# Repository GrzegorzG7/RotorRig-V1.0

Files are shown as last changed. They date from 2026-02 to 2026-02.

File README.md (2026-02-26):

# RotorRig — DIY BLDC Motor & Prop Test Bench

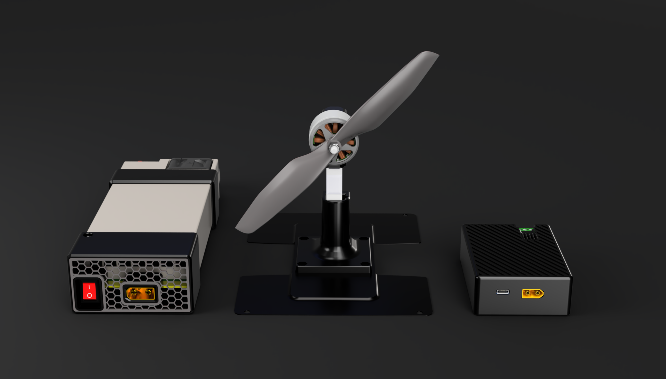
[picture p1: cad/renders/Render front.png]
RotorRig CAD render


RotorRig is a compact DIY platform for **repeatable testing of BLDC motors and propellers**.  
It streams data over USB as **CSV**, so you can compare setups (motor/prop/ESC/voltage) with real numbers instead of “feels faster”.

**What it does:**
- **Thrust**: load cell + HX711  
- **Electrical**: voltage / current / power via INA226 + shunt  
- **RPM**: BDShot telemetry (when ESC/firmware supports it)  
- **Logging**: CSV over Serial (examples in `logs/examples/`)

Full build journey + context: https://blueprint.hackclub.com/projects/7240

---

## Why I made it
I built RotorRig to get **repeatable, apples-to-apples comparisons** between motors and props (and later: to validate experiments like custom windings/stators).  
With the same test profile and measurement chain, it’s much easier to judge performance, efficiency, and tuning changes objectively.

---

## Safety
This spins real props — treat it like a power tool.
- Keep a clear area around the rig
- Wear eye protection
- Secure the rig to a heavy base
- First tests: low throttle / no prop

---

## Repository structure
- `cad/`
  - `export_step/` → full assembly `.STEP`
  - `source/` → Fusion 360 source `.f3z`
  - `stl/` → printable STLs
  - `renders/` → renders used below
- `docs/`
  - `images/` → build photos
  - `wiring/` → wiring diagram
- `kicad/` → schematic / connections in KiCad
- `firmware/` → PlatformIO project (RP2040)
- `logs/examples/` → example CSV logs
- `BOM.csv` → full BOM

---

## Pictures

### CAD renders
<p align="center">
  
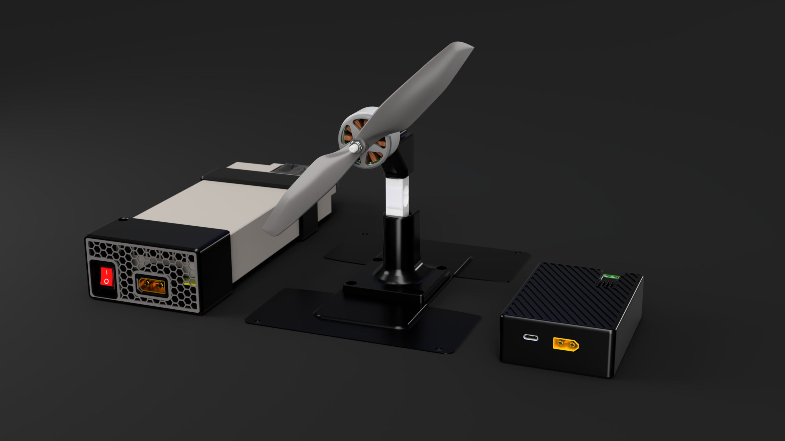
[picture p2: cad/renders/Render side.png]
  
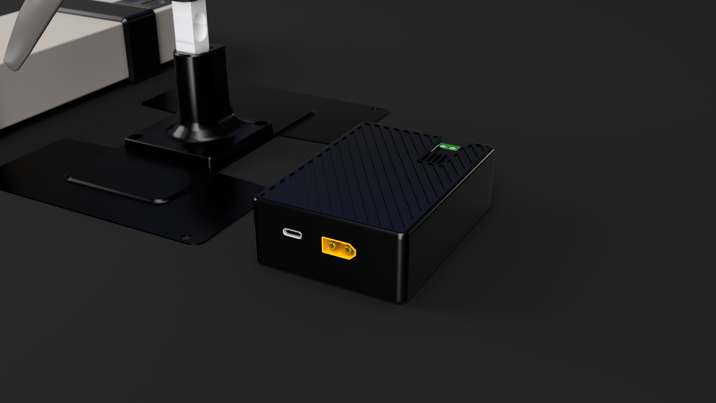
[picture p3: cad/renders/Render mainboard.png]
  
</p>

### Build photos
<p align="center">
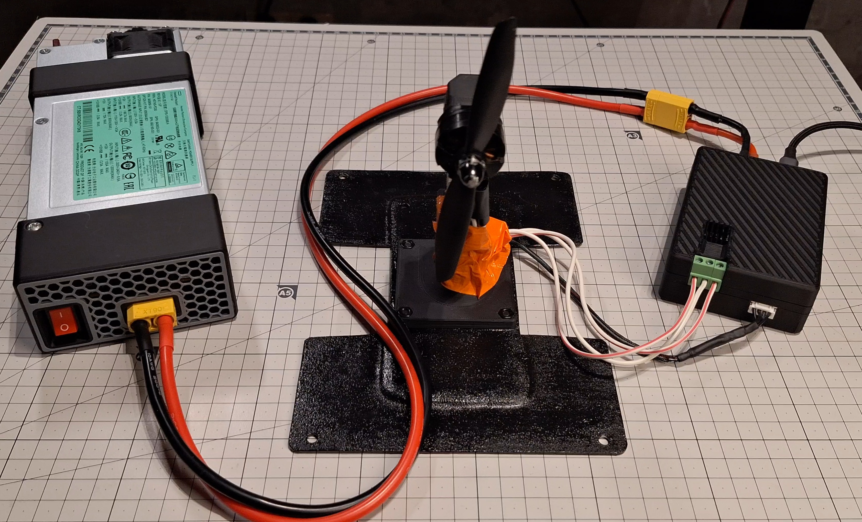
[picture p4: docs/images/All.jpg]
  
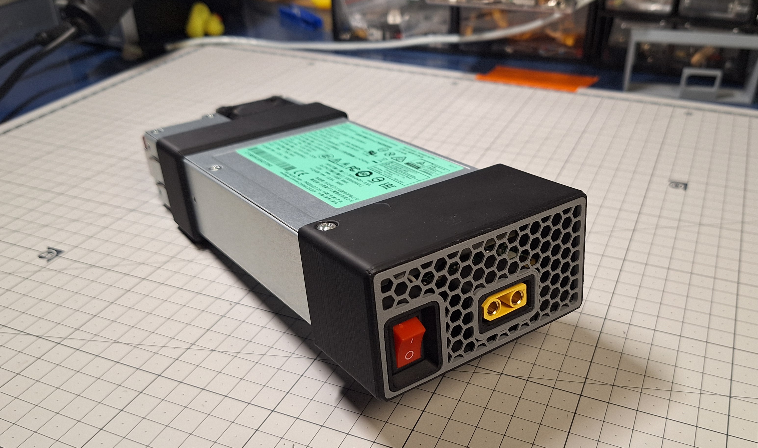
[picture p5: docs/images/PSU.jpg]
  
</p>
<p align="center">
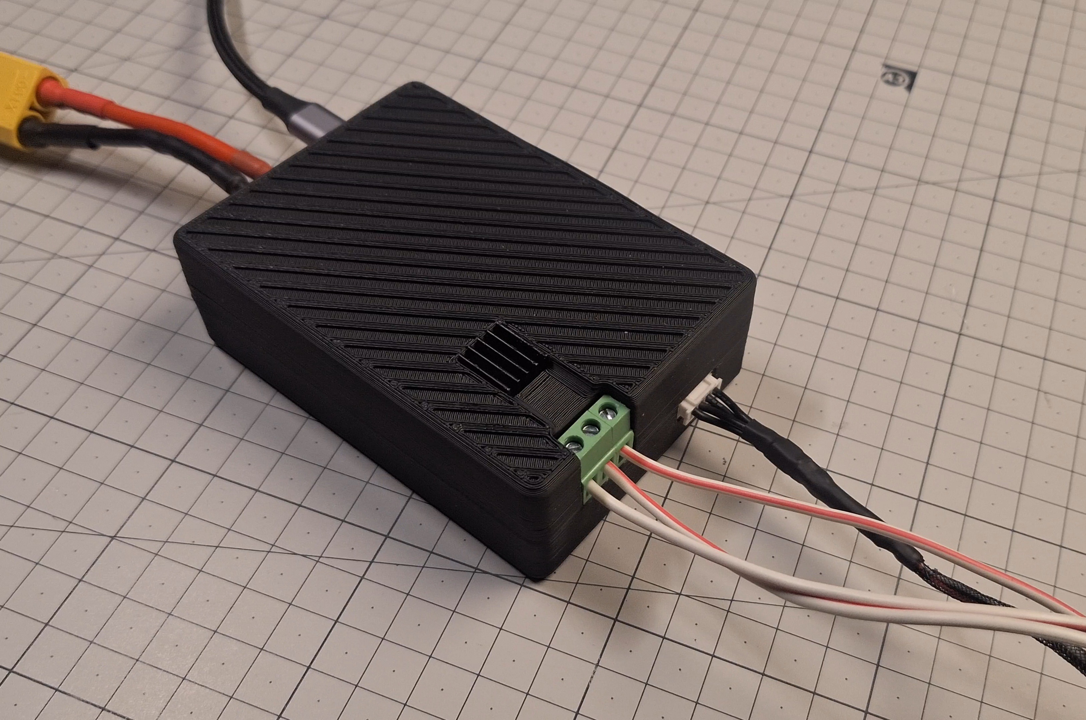
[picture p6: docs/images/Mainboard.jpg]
  
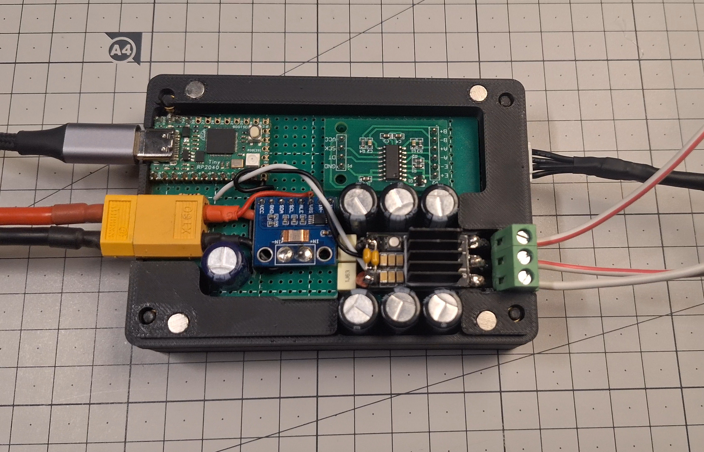
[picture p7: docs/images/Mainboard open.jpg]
  
</p>

### Wiring diagram
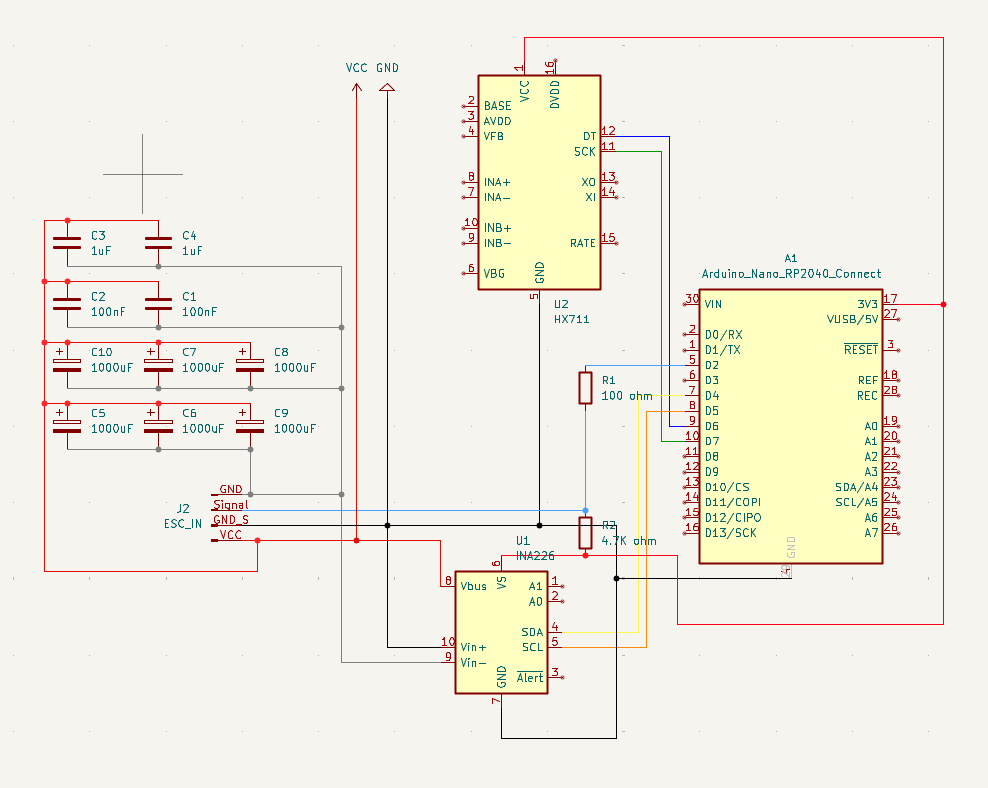
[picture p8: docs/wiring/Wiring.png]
Wiring diagram


---

## How to build (from scratch)

### 1) 3D print the parts
All STLs are in `cad/stl/`:
- `cad/stl/Bench/` (load cell holders)
- `cad/stl/Mainboard/` (electronics enclosure)
- `cad/stl/Power supply/` (PSU stand/cover)

**Print settings used (my build):**

**ABS / ABS+ (enclosures + structural parts)**
- Layer height: **0.2 mm**
- Walls: **4**
- Infill: **40%**

**TPU (rubber feet)**
- Layer height: **0.2 mm**
- Walls: **2**
- Infill: **100%**

Hardware (inserts/screws/magnets): see **BOM**.

### 2) Mechanical assembly
- Mount the load cell using the printed holders (bench parts are in `cad/stl/Bench/`)
- Mount the motor securely and keep the thrust direction aligned with the load cell
- Make sure nothing can touch the prop (wires, zip-ties, enclosure edges, etc.)

### 3) Electronics & wiring
This version uses **perfboard + off-the-shelf modules** (no custom manufactured PCB required).
- Wiring diagram: `docs/wiring/Wiring.png`
- KiCad project files are in `kicad/` (Mainboard.kicad_pro + Mainboard.kicad_sch)

### 4) Firmware (PlatformIO)
Target MCU: **WisdPi Tiny RP2040** (RP2040).  
The PlatformIO environment is set up as `board = pico`, which works for Pico-class RP2040 boards.

From the `firmware/` directory:

```bash
pio run -t upload
```

Serial monitor (115200):

```bash
pio device monitor
```

---

## How to use (typical workflow)

### 1) Connect everything
- motor ↔ ESC ↔ PSU/battery  
- RP2040 ↔ USB to PC  

Open Serial @ **115200**.

### 2) Set metadata (saved into every CSV row)
```text
setmeta <test_id> <motor_id> <kv> <prop> <battery_s> <esc_fw> <pole_pairs>
```

Example:
```text
setmeta T_CORE M_3115 900 APC8x4E 4 LANRC45A 7
```

### 3) Calibration / tare
- **Calibration** (`cal ...` + `save`) is usually done **once** (or after hardware changes).
- **Tare** should be done **before each test**.

Tare:
```text
tare
```

If you need to calibrate:
```text
cal <mass_g>
save
```

### 4) Run a test (core profile)
```text
start
autotest core
```

Stop anytime:
```text
stop
```

Emergency stop:
```text
estop
```

Command list:
```text
help
```

---

## CSV logs
RotorRig prints CSV rows over Serial. Example logs are in `logs/examples/`.

The CSV header includes (among others):
- `throttle_pct`, `RPM`, `V_bus_V`, `I_A`, `P_in_W`, `thrust_g`, `eff_g_per_W`, and metadata from `setmeta`.

---

## BOM (Bill of Materials)
Full BOM is in `BOM.csv`.

| Line | Category | Qty | Unit | Part | Manufacturer | MPN | Link |
|---:|---|---:|---|---|---|---|---|
| 1 | MCU / Control | 1 | pcs | Tiny RP2040 dev board (RP2040) | WisdPi | Tiny RP2040 (WP-2040T) | https://www.wisdpi.com/products/wisdpi-tiny-rp2040-a-tiny-cool-rp2040-dev-board-with-4mb-flash |
| 2 | Drive | 1 | pcs | ESC 45A 2–6S (BLHeli_S / DShot) | LANRC | LANRC 45A BLHeli_S 2-6S ESC | https://pl.banggood.com/LANRC-35A-or-45A-BLHeli_S-2-6S-ESC-with-RGB-LEDs-Supports-DShot150-300-600-for-FPV-Racing-Drone-p-2045658.html |
| 3 | Sensing | 1 | pcs | HX711 load cell amplifier module (24-bit ADC) | Generic / Kamami | HX711 module | https://kamami.pl/czujniki-nacisku/561387-wzmacniacz-konwerter-sygnalu-tensometru-z-ukladem-hx711-5906623473342.html |
| 4 | Sensing | 1 | pcs | INA226 current/voltage/power monitor module (I2C) | Generic / Kamami | INA226 module | https://kamami.pl/en/current-sensors/573164-module-with-ina226-current-sensor-5906623456505.html |
| 5 | Sensing | 1 | pcs | Load cell 10kg straight bar (TAL220 type) | SparkFun | SEN-13329 (TAL220 10kg) | https://www.sparkfun.com/load-cell-10kg-straight-bar-tal220.html |
| 6 | Power (DC-link) | 6 | pcs | Electrolytic capacitor low-ESR 1000µF 25V (DC-link bank) | Panasonic | EEUFR1E102B | https://www.tme.eu/en/details/eeufr1e102b/tht-electrolytic-capacitors/panasonic/ |
| 7 | Power (HF decoupling) | 2 | pcs | MLCC capacitor 1µF 50V X7R 1206 (near ESC) | Yageo | CC1206KKX7R9BB105 | https://www.tme.eu/pl/details/cc1206kkx7r9105/kondensatory-mlcc-smd/yageo/cc1206kkx7r9bb105/ |
| 8 | Power (snubber) | 2 | pcs | Film capacitor 100nF 63V (snubber/HF) | KEMET | R82DC3100AA50K | https://www.tme.eu/pl/details/r82dc3100aa50k/kondensatory-foliowe-tht/kemet/ |
| 9 | Passives | 1 | pcs | Resistor 100Ω 0.25W 1% THT | ROYALOHM | MF0S4FF1000A50 | https://www.tme.eu/en/details/mf0s4ff1000a50/tht-resistors/royalohm/ |
| 10 | Passives | 1 | pcs | Resistor 4.7kΩ 0.25W 1% THT | ROYALOHM | MF0S4FF4701A50 | https://www.tme.eu/en/details/mf0s4ff4701a50/tht-resistors/royalohm/ |
| 11 | PSU mod | 1 | pcs | Resistor 13.3kΩ 0.25W 1% THT (voltage adjust mod) | ROYALOHM | MF0S4FF1332A50 | https://www.tme.eu/lv/details/mf0s4ff1332a50/rezistori-tht/royalohm/ |
| 12 | PSU mod | 1 | pcs | Resistor 47kΩ 0.25W 1% THT (OVP adjust mod) | ROYALOHM | MF0S4FF4702A50 | https://www.tme.eu/en/details/mf0s4ff4702a50/tht-resistors/royalohm/ |
| 13 | INA226 shunt | 1 | pcs | Current sense resistor 1mΩ 3W 1% 2512 | Bourns | CRE2512-FZ-R001E-3 | https://www.digikey.com/en/products/detail/bourns-inc/CRE2512-FZ-R001E-3/4900069 |
| 14 | Connectors | 1 | pair | XT60 connector pair (male+female) | AMASS | XT60 (pair) | https://avifly.pl/en/connectors-and-wires/xt60-para-amass |
| 15 | Connectors | 1 | pair | XT90 connector pair (male+female) | AMASS | XT90H-M + XT90H-F | https://www.tme.eu/en/details/xt90h-f/dc-power-connectors/amass/ |
| 16 | UI / Power | 1 | pcs | Rocker switch KCD1 21x15mm ON/OFF (2-pin) | Generic | KCD1 21x15 ON/OFF | https://abc-rc.pl/en/products/przelacznik-kolyskowy-bistabilny-kcd1-czarny-21x15mm-przelacznik-on-off-250v-2pin-16579.html |
| 17 | Connectors | 1 | pcs | PCB screw terminal 3-pin 5.0/5.08mm pitch | Degson | DG128-5.0-03P-14-00A(H) | https://www.tme.eu/en/details/dg128-5.0-03p14/pcb-terminal-blocks/degson-electronics/dg128-5-0-03p-14-00a-h/ |
| 18 | Connectors | 1 | pcs | JST XH 4-pin header, vertical, 2.5mm (male) | JST | B4B-XH-A(LF)(SN) | https://www.tme.eu/en/details/b4b-xh-a/raster-signal-connectors-2-50mm/jst/b4b-xh-a-lf-sn/ |
| 19 | Connectors | 1 | pcs | JST XH 4-pin housing (female) | JST | XHP-4 | https://www.tme.eu/en/details/xhp-4/raster-signal-connectors-2-50mm/jst/ |
| 20 | Prototyping | 1 | pcs | Universal prototyping PCB, 100x70mm (FR4, 2.54mm holes) | Generic / Kamami | 100x70 perfboard | https://kamami.pl/en/Universal-soldering-boards/583012-double-sided-universal-board-with-825-holes-5906623460908.html |
| 21 | Mechanical | 8 | pcs | Neodymium disc magnet 5x2mm | Euromagnesy | MW 5x2 N38 | https://euromagnesy.com/pl/magnesy-walcowe-o-2-mm-o-10-mm/137-mw-5-x-2-n38-5905072502528.html |
| 22 | Mechanical | 4 | pcs | Heat-set threaded insert M3, length ~4mm | Tappex | 145M3 (example) | https://www.adafruit.com/product/4255 |
| 23 | Fasteners | 4 | pcs | Screw M3x20 | Generic | DIN 912 / ISO 4762 | https://allegro.pl/listing?string=%C5%9Bruba%20imbusowa%20M3x20%20DIN%20912 |
| 24 | Fasteners | 4 | pcs | Nut M4 | Generic | DIN 934 | https://allegro.pl/listing?string=nakr%C4%99tka%20M4%20DIN%20934 |
| 25 | Fasteners | 4 | pcs | Screw M4x8 | Generic | DIN 912 / ISO 4762 | https://allegro.pl/listing?string=%C5%9Bruba%20imbusowa%20M4x8%20DIN%20912 |
| 26 | Fasteners | 2 | pcs | Screw M4x12 | Generic | DIN 912 / ISO 4762 | https://allegro.pl/listing?string=%C5%9Bruba%20imbusowa%20M4x12%20DIN%20912 |
| 27 | Fasteners | 2 | pcs | Screw M5x20 | Generic | DIN 912 / ISO 4762 | https://allegro.pl/listing?string=%C5%9Bruba%20imbusowa%20M5x20%20DIN%20912 |
| 28 | Power (recommended) | 1 | pcs | Server PSU 1200W 12V (modified to ~14.8V) | HP | DPS-1200SB-A / HSTNS-PD30 | https://ripe.pl/pl/p/Zasilacz-HP-DPS-1200SB-A-HSTNS-PD30-6439956-101-1200W/16723 |

---

## License
This project is licensed under **CC BY-NC-SA 4.0** (Attribution-NonCommercial-ShareAlike).  
You can build, modify and share it for non-commercial use with attribution, and derivatives must use the same license.

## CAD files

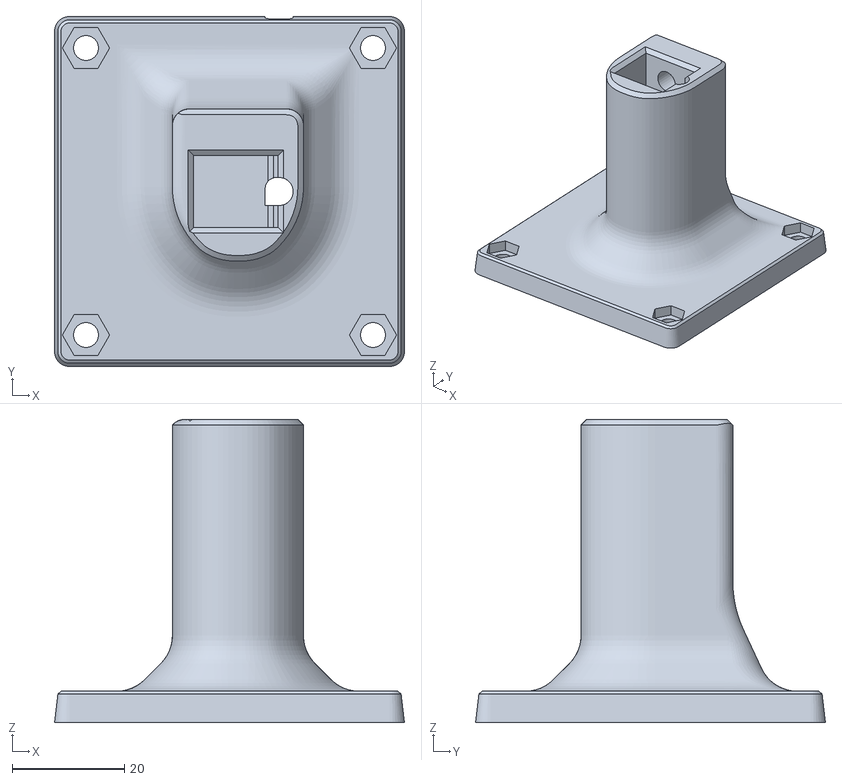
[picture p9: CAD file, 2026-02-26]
cad/stl/Bench/bottom load cell holder.stl
62.3 x 62.3 x 54.0

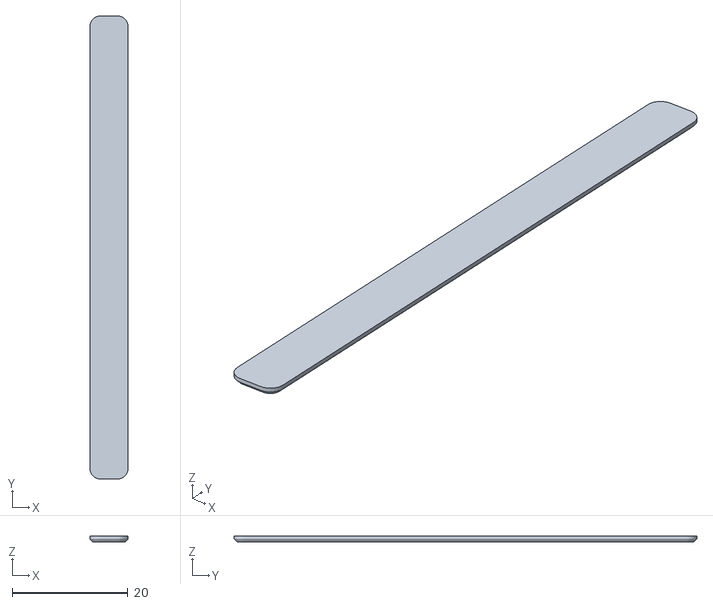
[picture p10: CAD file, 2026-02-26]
cad/stl/Mainboard/feet.stl
6.60 x 79.9 x 1.00

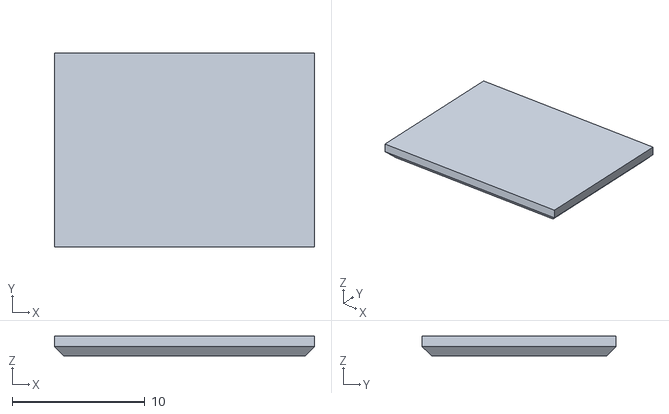
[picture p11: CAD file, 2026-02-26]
cad/stl/Power supply/feet.stl
19.6 x 14.6 x 1.50

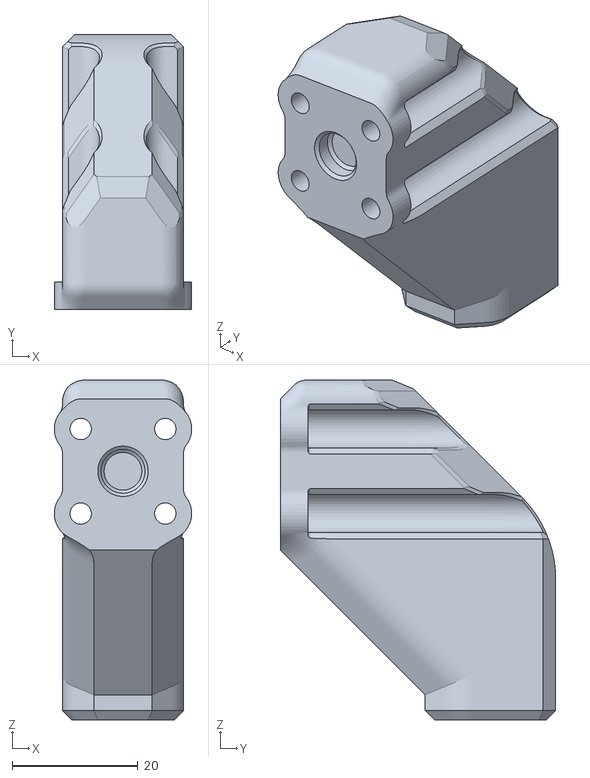
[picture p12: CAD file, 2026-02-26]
cad/stl/Bench/top load cell holder.stl
21.8 x 43.7 x 54.0

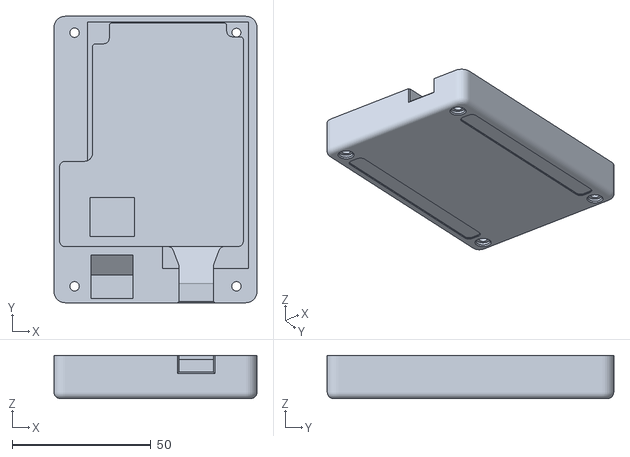
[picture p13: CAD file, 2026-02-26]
cad/stl/Mainboard/Bottom case.stl
73.1 x 103.1 x 15.5

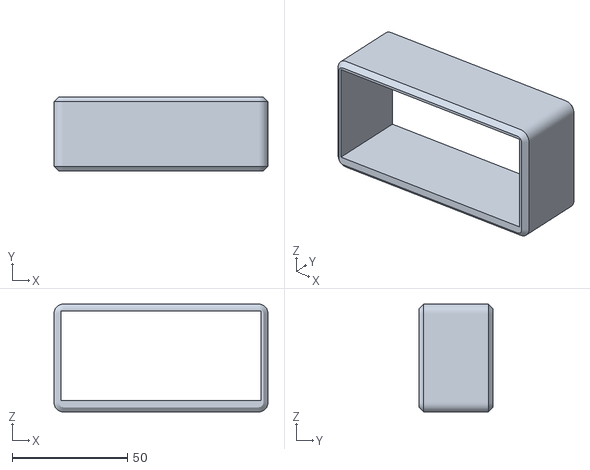
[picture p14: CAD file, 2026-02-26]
cad/stl/Power supply/back psu stand.stl
92.7 x 32.0 x 46.7

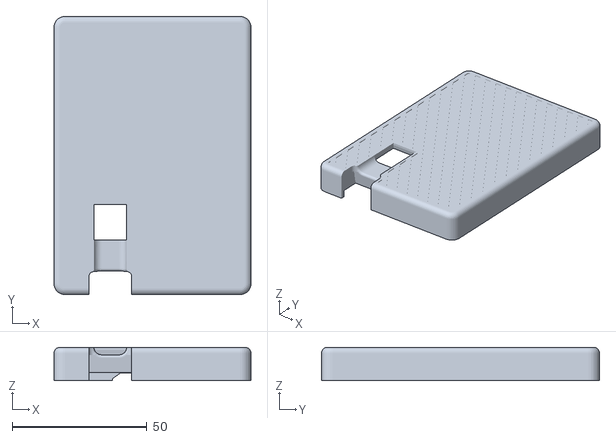
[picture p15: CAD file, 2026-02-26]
cad/stl/Mainboard/Top case.stl
73.1 x 103.1 x 12.4

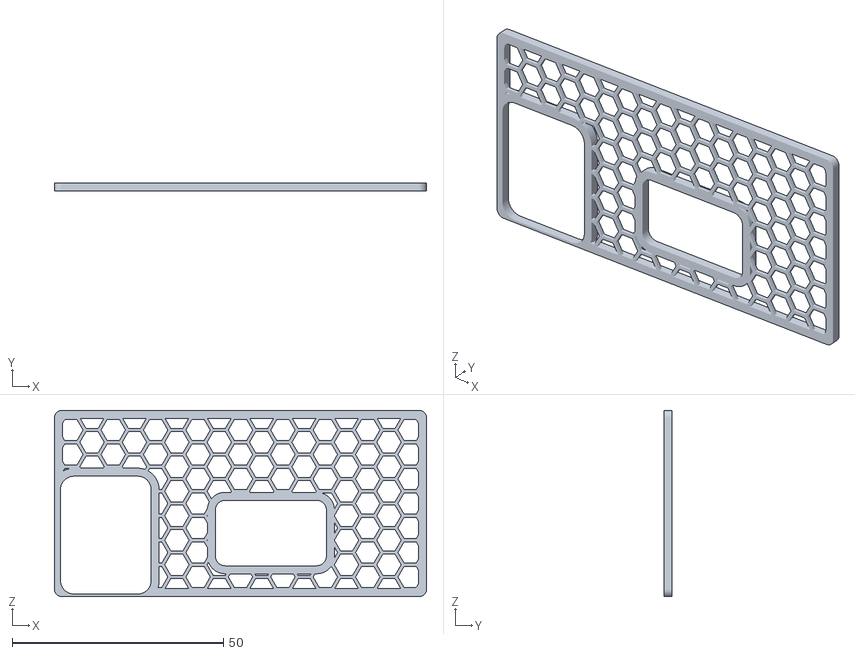
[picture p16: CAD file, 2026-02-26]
cad/stl/Power supply/front psu grill.stl
88.1 x 2.00 x 44.1

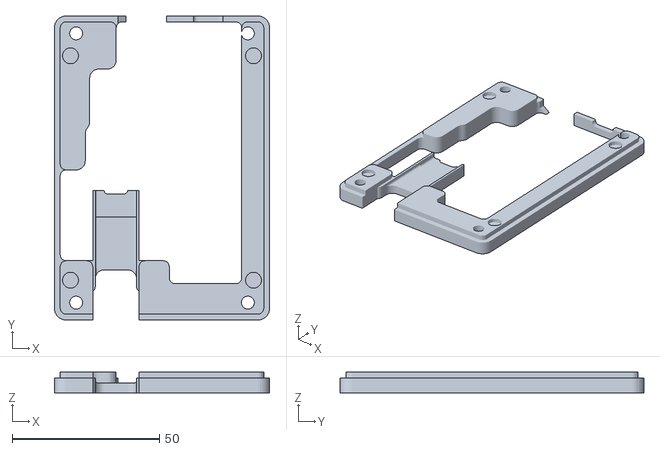
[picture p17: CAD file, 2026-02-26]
cad/stl/Mainboard/Middle case.stl
73.1 x 103.1 x 7.00

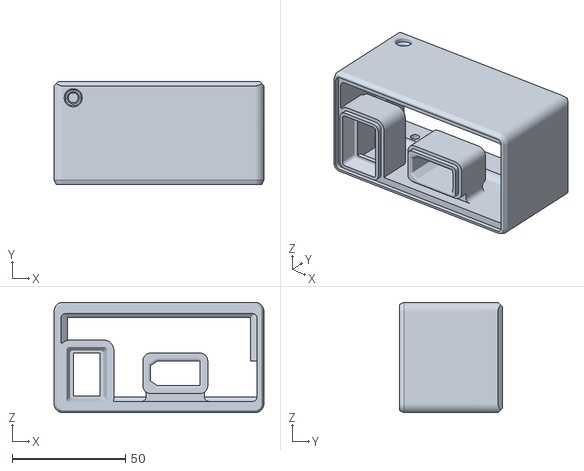
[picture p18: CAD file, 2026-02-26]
cad/stl/Power supply/front psu cover.stl
92.7 x 45.5 x 48.7

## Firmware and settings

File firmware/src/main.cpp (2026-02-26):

#include <Arduino.h>

#include "cfg.h"
#include "frame.h"
#include "meta.h"
#include "csv.h"

#include "esc_bdshot.h"
#include "sensors_hx711.h"
#include "sensors_ina226.h"
#include "cli.h"
#include "autotest.h"

static EscBdshot esc;
static SensorsHx711 hx;
static SensorsIna226 ina;
static CLI cli;
static AutoTest autotest;
static Meta meta;

static uint32_t last_log_ms = 0;

static inline uint32_t now_ms() { return millis(); }
static inline uint32_t ms_since(uint32_t t0) { return (uint32_t)(millis() - t0); }

// === Hardware ===
static constexpr uint8_t HX_DOUT_GPIO = 6;
static constexpr uint8_t HX_SCK_GPIO  = 7;
static constexpr uint8_t ESC_GPIO     = 2;
static constexpr uint8_t INA226_I2C_ADDR = 0x40;

static uint32_t last_hx_sample_count = 0;

void setup() {
  Serial.begin(SERIAL_BAUD);
  delay(200);

  hx.begin(HX_DOUT_GPIO, HX_SCK_GPIO);
  ina.begin(INA226_I2C_ADDR, SHUNT_OHMS, INA_EXPECTED_MAX_CURRENT_A);

  esc.begin(ESC_GPIO, DSHOT_SPEED);
  esc.setPolePairs(meta.pole_pairs);

  cli.begin();
  cli.bind(&esc, &hx, &ina, &meta, &autotest);

  last_log_ms = now_ms();
}

void loop() {
  // 1) ESC MUST tick fast (send throttle + pull telemetry)
  esc.tickFast();

  // 2) HX tick fast
  hx.tickFast();

  // push to rolling HX window only when NEW sample arrives
  const uint32_t sc = hx.sampleCount();
  if (sc != last_hx_sample_count) {
    last_hx_sample_count = sc;
    hx.windowPush(hx.lastRaw());
  }

  // 3) Other periodic logic
  autotest.tick(esc);
  cli.tick();

  // 4) Log/status update at LOG_PERIOD_MS
  const uint32_t now = now_ms();
  if (ms_since(last_log_ms) >= LOG_PERIOD_MS) {
    last_log_ms = now;

    Frame f;
    f.t_ms = now;

    // Autotest context (useful for post-processing)
    if (autotest.active()) {
      f.step_id = autotest.stepId();
      f.step_time_s = autotest.stepTimeS();
      f.is_steady = autotest.isSteady() ? 1 : 0;
    }

    // ESC telemetry
    auto tel = esc.getTelemetry();
    f.erpm = tel.erpm;
    f.rpm = tel.rpm;
    f.bdshot_err_pct = tel.bdshot_err_pct;

    // INA
    InaSample is = ina.read();
    f.v_bus_V = is.v_bus_V;
    f.i_A = is.i_A;
    f.p_in_W = is.p_W;

    // HX noise + thrust (ROLLING WINDOW, no reset here)
    auto nz = hx.windowNoise();
    f.hx_noise_pp = nz.valid ? nz.raw_pp : -1;

    int32_t raw_for_thrust = hx.lastRaw();
    if (hx.windowHasEnough(4)) {
      raw_for_thrust = hx.windowTrimmedMean(20); // 20% trim
    }

    HxSample hs = hx.convertRawToSample(raw_for_thrust);
    if (hs.valid && isfinite(hs.thrust_g) && isfinite(hs.thrust_N)) {
      f.thrust_g = hs.thrust_g;
      f.thrust_N = hs.thrust_N;
    } else {
      f.thrust_g = NAN;
      f.thrust_N = NAN;
    }

    // efficiencies
    if (isfinite(f.thrust_g) && isfinite(f.p_in_W) && f.p_in_W > 0.1f) f.eff_g_per_W = f.thrust_g / f.p_in_W;
    if (isfinite(f.thrust_N) && isfinite(f.p_in_W) && f.p_in_W > 0.1f) f.eff_N_per_W = f.thrust_N / f.p_in_W;
    if (isfinite(f.thrust_g) && isfinite(f.i_A) && fabsf(f.i_A) > 0.01f) f.eff_g_per_A = f.thrust_g / f.i_A;

    f.throttle_pct = esc.currentThrottlePct();

    // update CLI live snapshot for STATUS
    cli.setLive(
      f.thrust_g, f.thrust_N,
      f.v_bus_V, f.i_A, f.p_in_W,
      f.erpm, f.rpm, f.bdshot_err_pct,
      hx.lastRaw(), hx.offset(), hx.scaleCountsPerG(),
      hx.calValid(), hx.inverted(),
      f.hx_noise_pp
    );

    if (cli.csvOn()) {
      printCsvFrame(f, meta, esc, cli.notes());
    }
  }
}

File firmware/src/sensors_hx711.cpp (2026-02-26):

#include "sensors_hx711.h"
#include <math.h>

SensorsHx711::SensorsHx711() {
  for (uint8_t i = 0; i < WIN_MAX; i++) window_[i] = 0;
}

bool SensorsHx711::begin(uint8_t dout_gpio, uint8_t sck_gpio) {
  storage_.begin();

  static HX711_ADC lc(dout_gpio, sck_gpio);
  lc_ = &lc;

  lc_->begin();
  lc_->start(2000, false);

  // load calibration if present
  CalData tmp;
  if (storage_.load(tmp)) {
    cal_ = tmp;
    applyCalToLibrary_();
  } else {
    cal_ = CalData{};
    // keep library in harmless defaults
    lc_->setCalFactor(1.0f);
    lc_->setTareOffset(0);
  }

  // prime a bit
  const uint32_t t0 = millis();
  while (millis() - t0 < 200) {
    lc_->update();
    yield();
  }

  sample_count_ = 0;
  last_raw_counts_ = 0;
  tare_busy_ = false;
  tare_done_flag_ = false;
  cal_busy_ = false;
  cal_done_flag_ = false;

  windowReset();
  return true;
}

void SensorsHx711::applyCalToLibrary_() {
  if (!lc_ || !calValid()) return;
  lc_->setTareOffset(cal_.offset);
  const float cf = cal_.invert ? -cal_.scale : cal_.scale; // signed for library
  lc_->setCalFactor(cf);
}

void SensorsHx711::tickFast() {
  if (!lc_) return;

  if (lc_->update()) {
    // getData() returns (raw - offset)/calFactor
    const float val = lc_->getData();

    // reconstruct raw counts regardless of calibration state
    // if cal valid -> raw = offset + val*calFactor
    // else (cal invalid) library calFactor=1, offset=0 -> raw ~= val
    float cf = 1.0f;
    int32_t off = 0;

    if (calValid()) {
      cf = cal_.invert ? -cal_.scale : cal_.scale;
      off = cal_.offset;
    } else {
      // try to use whatever library currently has (defaults at boot are 1 and 0)
      cf = lc_->getCalFactor();
      off = (int32_t)lc_->getTareOffset();
      if (!isfinite(cf) || cf == 0.0f) cf = 1.0f;
    }

    if (isfinite(val)) {
      last_raw_counts_ = (int32_t)lrintf((float)off + val * cf);
    }

    sample_count_++;
  }

  // tare completion
  if (tare_busy_ && lc_->getTareStatus()) {
    cal_.offset = (int32_t)lc_->getTareOffset();
    tare_busy_ = false;
    tare_done_flag_ = true;

    // after tare, reset window so noise/mean restart cleanly
    windowReset();
  }
}

void SensorsHx711::tareTrimStart(uint16_t /*samples*/, uint8_t /*trim_pct*/) {
  if (!lc_) return;
  tare_busy_ = true;
  tare_done_flag_ = false;
  lc_->tareNoDelay();
}

bool SensorsHx711::tareTrimDoneConsume() {
  if (tare_done_flag_) {
    tare_done_flag_ = false;
    return true;
  }
  return false;
}

bool SensorsHx711::calibrateWithMass(float mass_g) {
  if (!lc_ || !(mass_g > 0.0f) || !isfinite(mass_g)) return false;

  if (!lc_->refreshDataSet()) return false;

  float newCal = lc_->getNewCalibration(mass_g);
  if (!isfinite(newCal) || newCal == 0.0f) return false;

  cal_.offset = (int32_t)lc_->getTareOffset();
  cal_.invert = (newCal < 0.0f);
  cal_.scale  = fabsf(newCal);
  cal_.valid  = true;

  applyCalToLibrary_();

  // after cal, reset window too
  windowReset();
  return true;
}

void SensorsHx711::calTrimStart(float mass_g, uint16_t /*samples*/, uint8_t /*trim_pct*/) {
  cal_busy_ = true;
  cal_done_flag_ = false;

  bool ok = calibrateWithMass(mass_g);

  cal_busy_ = false;
  cal_done_flag_ = ok;
}

bool SensorsHx711::calTrimDoneConsume() {
  if (cal_done_flag_) {
    cal_done_flag_ = false;
    return true;
  }
  return false;
}

float SensorsHx711::rawToGrams(int32_t raw) const {
  if (!calValid()) return NAN;
  float delta = (float)(raw - cal_.offset);
  if (cal_.invert) delta = -delta;
  return delta / cal_.scale;
}

HxSample SensorsHx711::convertRawToSample(int32_t raw) const {
  HxSample s;
  if (!calValid()) return s;
  const float g = rawToGrams(raw);
  if (!isfinite(g)) return s;
  s.valid = true;
  s.thrust_g = g;
  s.thrust_N = g * 0.00980665f;
  return s;
}

void SensorsHx711::windowReset() {
  window_head_ = 0;
  window_count_ = 0;
}

void SensorsHx711::windowPush(int32_t raw) {
  window_[window_head_] = raw;
  window_head_ = (uint8_t)((window_head_ + 1) % WIN_MAX);
  if (window_count_ < WIN_MAX) window_count_++;
}

void SensorsHx711::copyWindowToLinear_(int32_t* out, uint8_t& n) const {
  n = window_count_;
  if (n == 0) return;

  // oldest index = head - count (mod WIN_MAX)
  int start = (int)window_head_ - (int)window_count_;
  while (start < 0) start += WIN_MAX;

  for (uint8_t i = 0; i < n; i++) {
    int idx = start + i;
    if (idx >= WIN_MAX) idx -= WIN_MAX;
    out[i] = window_[idx];
  }
}

int32_t SensorsHx711::windowTrimmedMean(uint8_t trim_pct) const {
  if (window_count_ == 0) return last_raw_counts_;

  int32_t tmp[WIN_MAX];
  uint8_t n = 0;
  copyWindowToLinear_(tmp, n);
  if (n == 0) return last_raw_counts_;

  // insertion sort
  for (uint8_t i = 1; i < n; i++) {
    int32_t key = tmp[i];
    int j = (int)i - 1;
    while (j >= 0 && tmp[j] > key) { tmp[j + 1] = tmp[j]; j--; }
    tmp[j + 1] = key;
  }

  uint8_t k = (uint8_t)((uint16_t)n * (uint16_t)trim_pct / 100U);
  if (k * 2 >= n) k = 0;

  const uint8_t a = k;
  const uint8_t b = (uint8_t)(n - k);
  if (b <= a) return tmp[n / 2];

  int64_t sum = 0;
  uint32_t used = 0;
  for (uint8_t i = a; i < b; i++) { sum += tmp[i]; used++; }
  return (used > 0) ? (int32_t)(sum / (int64_t)used) : tmp[n / 2];
}

HxNoise SensorsHx711::computeNoiseFromWindow_() const {
  HxNoise ns{};
  if (window_count_ < 4) return ns;

  int32_t tmp[WIN_MAX];
  uint8_t n = 0;
  copyWindowToLinear_(tmp, n);
  if (n < 4) return ns;

  int32_t mn = tmp[0], mx = tmp[0];
  double sum = 0.0;
  for (uint8_t i = 0; i < n; i++) {
    int32_t v = tmp[i];
    if (v < mn) mn = v;
    if (v > mx) mx = v;
    sum += (double)v;
  }
  double mean = sum / (double)n;

  double acc = 0.0;
  for (uint8_t i = 0; i < n; i++) {
    double d = (double)tmp[i] - mean;
    acc += d * d;
  }

  ns.valid = true;
  ns.raw_pp = (int32_t)(mx - mn);
  ns.std_counts = (n > 1) ? (float)sqrt(acc / (double)(n - 1)) : 0.0f;

  if (calValid()) {
    float p2p_g = (float)ns.raw_pp / cal_.scale;
    float std_g = ns.std_counts / cal_.scale;
    ns.stable = (p2p_g <= 2.0f) || (std_g <= 0.5f);
  } else {
    ns.stable = (ns.raw_pp < 1500);
  }

  return ns;
}

HxNoise SensorsHx711::windowNoise() const {
  return computeNoiseFromWindow_();
}

bool SensorsHx711::saveCal() {
  if (!calValid()) return false;
  return storage_.save(cal_);
}

bool SensorsHx711::loadCal() {
  CalData tmp;
  if (!storage_.load(tmp)) return false;
  cal_ = tmp;
  applyCalToLibrary_();
  windowReset();
  return true;
}

void SensorsHx711::resetCal() {
  cal_ = CalData{};
  storage_.reset();
  if (lc_) {
    lc_->setCalFactor(1.0f);
    lc_->setTareOffset(0);
  }
  windowReset();
}
